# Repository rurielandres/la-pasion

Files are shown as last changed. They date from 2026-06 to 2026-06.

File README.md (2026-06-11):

 Proyecto Minisumo - AD VICTORIAM

## 👥 Autores
- **Uriel Ramirez**   
- **Demian Ramirez** 
  
---

## 📖 Introducción#
El proyecto consiste en un robot minisumo autónomo que emplea distintos sensores para orientarse dentro del área de combate.  
- **Sensor frontal**: impulsa al robot hacia adelante para atacar.  
- **Sensores laterales**: permiten reorientarse frente a obstáculos o rivales.  
- **Sensor de piso**: asegura que el robot permanezca dentro de la arena de enfrentamiento.  

En conjunto, se trata de un mecanismo sencillo pero eficaz para la competencia de minisumo.

---

## ⚙️ Esquema en bloques
- Batería
- Sensor lateral
- Microcontrolador (ESP32 C3 mini)
- Sensor frontal
- Sensor de piso
- DRV8833 (Puente H)
- Motores

unnamed

---

## 💰 Componentes y costos aproximados
| Componente | Costo (ARS) |
|---|---|
| ESP32 C3 super mini | 10.000 |
| Batería de Lipo | 30.040 |
| TCRT5000 (sensor ) | 3.700 |
| AD-32 (sensor) x2 | 2.300 |
| Motores Pololu 250RPM x2 | 9.800 |
| DRV8833 (puente H) | 4.000 |
| Carrocería | 11.000 |
| hc sr04 | 3.500  |
| **Total** | **76.640**  |

---

## 🎯 Objetivo del Proyecto

El objetivo del robot minisumo *La Passione* es participar en competencias de sumo robótico, 
donde debe detectar, atacar y desplazar a su oponente fuera del área de combate (tatami).  
Para lograrlo, combina distintos sensores y un sistema de control basado en el ESP32 S3:

- **Atacar directamente** cuando el sensor frontal detecta un rival.  
- **Reorientarse** mediante los sensores laterales para enfrentar al oponente de manera estratégica.  
- **Mantenerse dentro del área de combate** gracias al sensor de piso que evita salidas accidentales.

unnamed (1)

 ---  
 
## 📐Diseño

Captura de pantalla 2026-06-11 085245

## Esquematico

Captura de pantalla 2026-06-11 083017

## PCB

Captura de pantalla 2026-06-11 082902

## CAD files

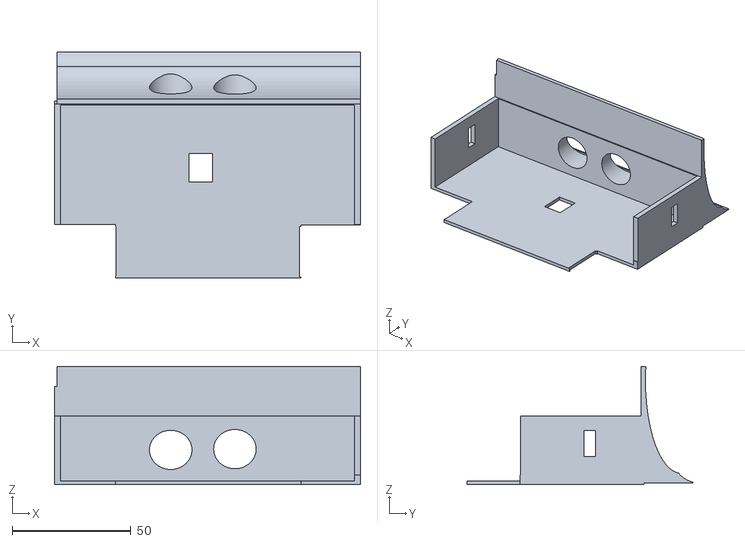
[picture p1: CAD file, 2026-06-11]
diseño 3d/Liberty Prime.stl
129.1 x 95.2 x 49.9

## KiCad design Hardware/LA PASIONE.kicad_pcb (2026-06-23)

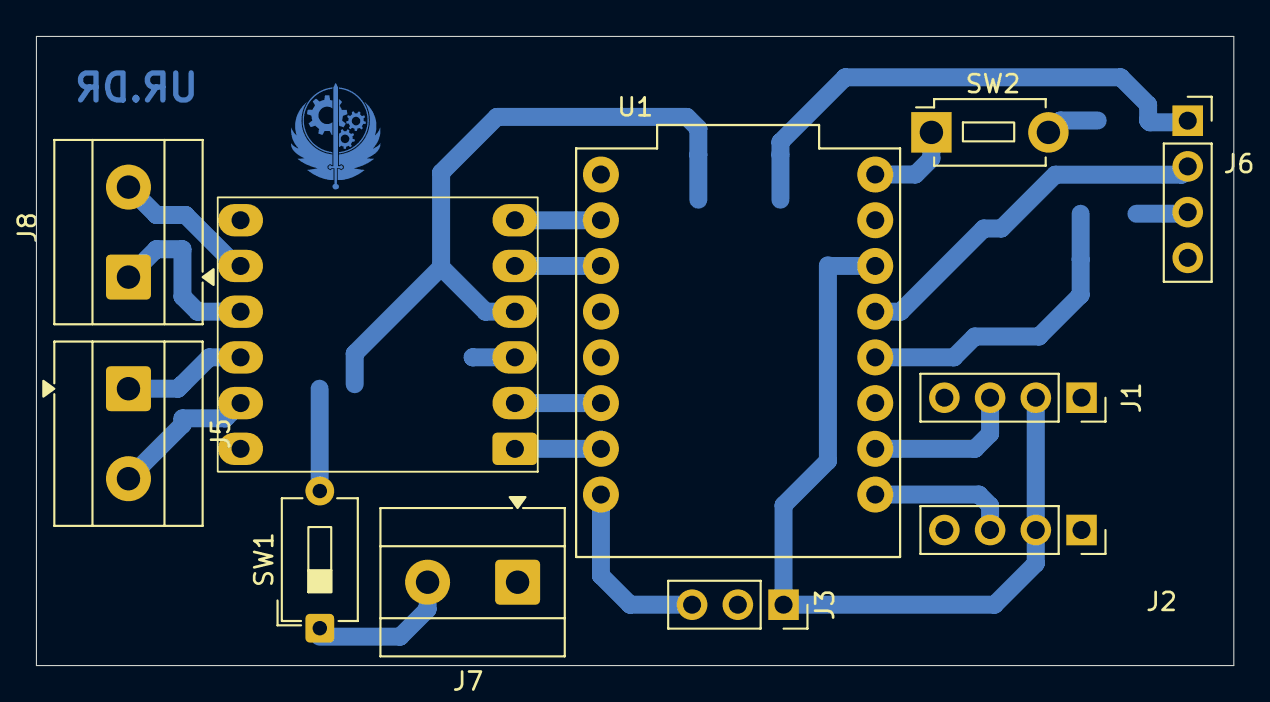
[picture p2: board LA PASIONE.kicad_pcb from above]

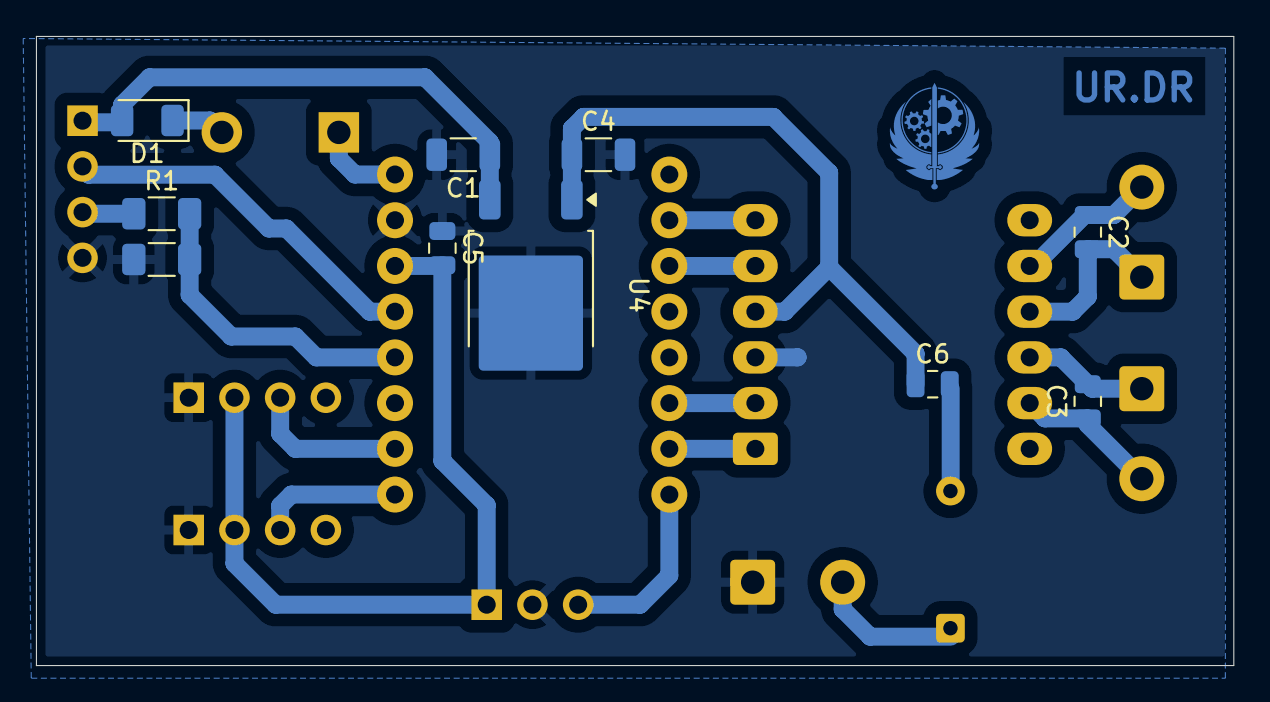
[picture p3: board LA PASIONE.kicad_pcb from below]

Board: 2 copper layers, 66.5 x 34.9 mm, 21 parts (10 on the bottom side), 21 nets.

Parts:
C1, C4: 10uF; C_1206_3216Metric
C2, C3, C5, C6: 100nF; C_0805_2012Metric
D1: 1n4007; D_1206_3216Metric
J1, J2, J6: Conn_01x04; PinSocket_1x04_P2.54mm_Vertical
J3: Conn_01x03; PinSocket_1x03_P2.54mm_Vertical
J5, J7, J8: Screw_Terminal_01x02; TerminalBlock_MetzConnect_Type055_RT01502HDWU_1x02_P5.00mm_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
R1: 1K; R_1206_3216Metric_Pad1.30x1.75mm_HandSolder
R2: 2K; R_1206_3216Metric_Pad1.30x1.75mm_HandSolder
SW1: SW_SPST; SW_DIP_SPSTx01_Slide_6.7x4.1mm_W7.62mm_P2.54mm_LowProfile
SW2: SW_Push; SW_PUSH_1P1T_6x3.5mm_H4.3_APEM_MJTP1243
U1: MODULE_ESP32-C3_SUPERMINI
U2: DRV8833
U4: L7805; TO-252-2

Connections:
+3.3V: C5.2, J1.2, J2.2, J3.1, U1.11 (3V3)
+5V: C1.1, D1.2 (A), J6.1, U4.3 (OUT)
/IN1: U1.2 (GPIO6), U2.6 (IN1)
/IN2: U1.3 (GPIO7), U2.5 (IN2)
/IN3: U1.6 (GPIO10), U2.2 (IN3)
/IN4: U1.7 (GPIO20), U2.1 (IN4)
/M1: C3.1, J5.2, U2.11 (OUT4)
/M2: C3.2, J5.1, U2.10 (OUT3)
/M3: C2.2, J8.1, U2.9 (OUT2)
/M4: C2.1, J8.2, U2.8 (OUT1)
/OutPut3: J2.3, U1.16 (GPIO0)
/OutPut4: J3.3, U1.8 (GPIO21)
/Output1: R1.2, R2.2, U1.13 (GPIO3)
/Output2: J1.3, U1.15 (GPIO1)
/TRIGGER: J6.2, U1.12 (GPIO4)
GND: C1.2, C4.2, C5.1, J1.1, J2.1, J3.2, J6.4, J7.1, R2.1, U1.10 (GND), U2.3 (GND), U4.2 (GND)
unnamed: D1.1 (K), SW2.2
unnamed: J6.3, R1.1
unnamed: J7.2, SW1.1 (A)
unnamed: SW2.1, U1.9 (5V)
VCC: C4.1, C6.1, SW1.2 (B), U2.4 (VCC), U4.1 (IN)

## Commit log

2026-05-06 Rename Fabulous Snicket-Trug.stl to Fabulous Snicket-Trug(desactualizado y corrompido)).stl
    [Fabulous Snicket-Trug(desactualizado y corrompido)).stl]
2026-06-11 Rename diseño 3d/Fabulous Snicket-Trug (3).stl to (NO SIRVE)
